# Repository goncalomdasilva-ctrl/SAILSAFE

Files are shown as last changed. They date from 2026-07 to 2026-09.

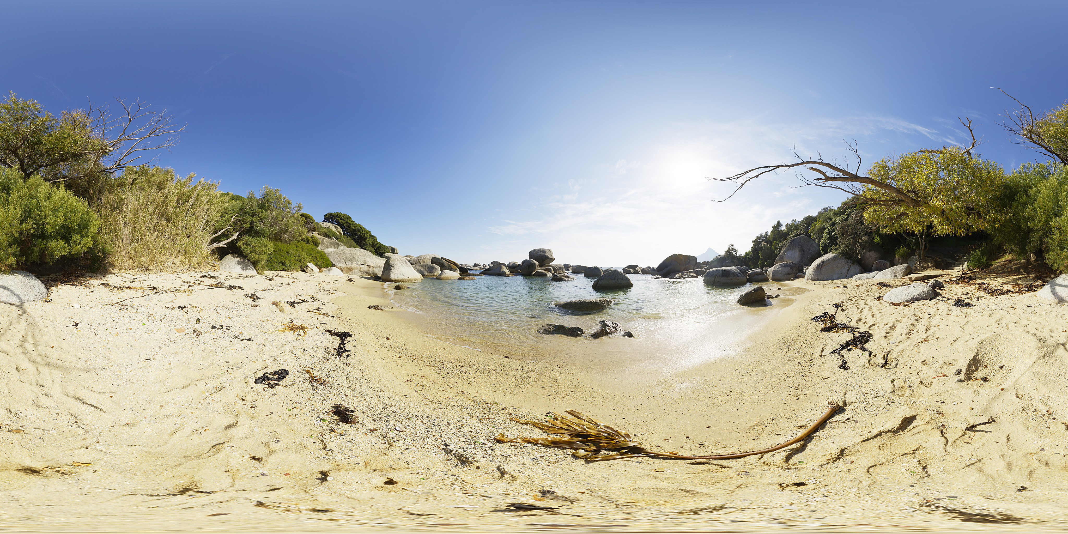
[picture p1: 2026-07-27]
website/assets/img/pano_mar.jpg

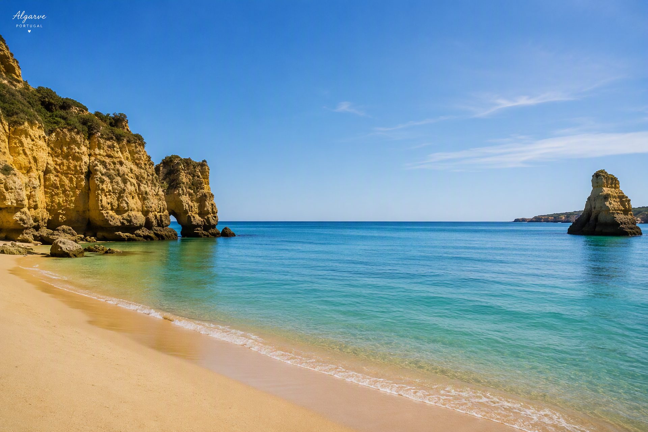
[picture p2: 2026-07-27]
website/assets/img/praia.jpg

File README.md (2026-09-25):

# SAILSAFE

Autonomous surface catamaran focused on control systems development.

## Overview
SAILSAFE is a personal engineering project focused on building an autonomous surface vehicle with differential propulsion, embedded control, and waypoint navigation. It is developed as a real-world platform for learning and applying control systems, embedded software and safety engineering.

> **Project history.** SAILSAFE has been in development since February 2026. The git
> history in this repository starts later than that — it was re-initialised during a
> restructure — so commit dates are not a record of the project's timeline. The actual
> development record, with dated entries from the start, is in
> [`Engineering_log.md`](Engineering_log.md).

> **On authorship.** The system design, the safety decisions, the hardware and the bench
> work are mine. The code is written with AI assistance and held to the same standard as
> everything else here: a regression suite that runs without hardware, and figures that
> come from measurements on the bench rather than from datasheets. The engineering log and
> the commit messages are also written with AI assistance, from my decisions and
> measurements. The log records those decisions and their reasoning — including the times
> a generated tool was wrong and the bench proved it.

## Current Phase
Phase 1 — software MVP validated in simulation, GPS integrated and validated on hardware. Propulsion on the bench next; mechanical build held until the structure is weighed (blueprint v6.1, CAD v6.4). **Where things stand and what comes next: see [Next steps](#next-steps) below and the latest entries of `Engineering_log.md`.**

## Current Status
- Raspberry Pi ↔ ESP32 command chain validated on the bench (USB serial, text protocol `L: x R: y`)
- State machine DISARMED ↔ ARMED / NAV with 5 Hz heartbeat; ESP32-side failsafe (~1 s timeout) confirmed with real hardware
- Heading hold (proportional controller) and waypoint navigation (haversine + bearing) validated in closed-loop simulation
- STOP retried until acknowledged by the ESP32; ARM/NAV refuse without proof the latch opened
- Control path independent of an interactive terminal (FIFO + `SIGUSR1`), so the process is
  commandable under systemd or `nohup`
- Per-session CSV logging with millisecond timestamps
- **GPS validated on hardware** (15 Sep): NEO-8M on the Pi's GPIO UART, 2 600 frames
  without a single bad checksum, fix with 8 satellites and HDOP 1.05. Short-term
  wander measured at ~30 cm over 10 s; slow drift over 10 min reached a 31 m × 4 m
  box at a window sill, with half the sky blocked — a pessimistic bound, to be
  re-measured on open water before the waypoint arrival radius is fixed
- **GPS integrated into the main process** (17 Sep, `--gps`): position read and
  logged in every state, not just NAV, so an ordinary bench session produces the
  dispersion data a separate script used to be needed for. Losing position in NAV
  leads to a safe state after a short tolerance; the return point is recorded at
  ARM. Rehearsed end to end against fake serial hardware (`tools/system_bench.py`),
  never yet against the real receiver
- **Heading blocked**: the BNO055 module is faulty (internal rail at 2.7 V with 4.7 V
  in, and ~0.4 mA of leakage on SDA, which poisoned the whole I2C bus). Replacement
  ordered; see `Engineering_log.md` for the diagnosis
- Power sense (ADS1015) written and covered by tests, and the chip answers reliably on
  the bus, but the dividers are not built yet — the PGA correction and the divider
  ratios stay theory until they are
- Mechanical architecture v6.1: batteries housed inside the hulls, IP66 electronics box at deck level
- Motors and ESCs in hand (each motor and waterjet is a single 107 g unit); loop key and fuse soldered. Bench test with the units **uncoupled** is next. Running them on water stays gated by the remote kill switch
- **Components weighed (25 Sep):** ~2.0 kg for everything except the structure, against 3.2 kg assumed by the CAD. The structure is still unweighed, so the total sits between 5.3 and 10.4 kg (waterline 33–65 mm). Battery bay floors raised from z=45 to **z=80**, which clears the whole range. Lighter propulsion may move the CG forward of the LCB and flip the trim to the bow, which would move the battery bays aft — to be decided after weighing the structure
- **30% throttle ceiling is per phase, not a constant:** bench 30%; tethered on water, higher; free running only with the remote kill switch. 30% throttle is roughly 30% of top speed (~0.5 m/s by a rough estimate), which a 1-knot current cancels
- GPS wiring closed (OPEN-005): NMEA on the Pi's GPIO UART, `/dev/serial0` at 9600
- Return point implemented (closes OPEN-006 on the point): the position is recorded
  once at ARM, averaged over validated fixes in a sliding window, and never rewritten.
  With `--gps`, ARM is refused without it. Straight-line return, which is only
  admissible on open water within sight of the operator. Recorded but not yet
  consumed — there is no return mode yet
- **Arrival radius is in debt to the GPS rate.** At 1 Hz, a position may legitimately
  be 2.5 s old; at the 3 m/s design speed that is 7.5 m of uncertainty, against a 4 m
  arrival radius. No staleness budget fixes this — raising the module to 5 Hz
  (`UBX-CFG-RATE`) is the condition for tightening the radius

## Next steps
*Updated 2026-09-25. The reasoning behind each item is in `Engineering_log.md`.*

1. **Bench test of ESCs and motors, uncoupled from the jets.** 30 A fuse, provided the
   holder's pigtail really is 14 AWG copper (not CCA); check polarity with a meter before
   the loop key goes in. 2–3 s pulses at 10–15%. Check rotation
   direction *before* coupling and mark the phase order. Measure the current. First run of
   the latch, failsafe, ceiling and confirmed STOP against real actuators.
2. **Thrust test in a tub**, jet submerged so the cooling loop primes, pulling on a spring
   scale. Replaces the speed estimate with a number.
3. **Weigh the structure** — a 3 mm okoumé offcut of known area, and the XPS. Then correct
   the mass table in `verify_concept.py` with measured values, recompute the CG, and
   decide the battery bay X position, confirm z=80, and the motor access hatch.
4. **Find the blueprint generator (OPEN-016)** and apply the changes to the drawing. Only
   then do the drawings go to the carpenter.

In parallel: run `main.py --gps --sim` on the Pi with the real receiver.
Blocked, nothing to do: replacement BNO055 board; remote kill switch (budget).

Open items: OPEN-014 (dead reckoning as observer, never actuator), OPEN-015 (bilge water
sensor per hull — the cooling loop puts pressurised water inside the hull), OPEN-016
(blueprint has no generator in the repo).

## Safety Design
- Boot always in a safe (DISARMED) state; STOP has absolute priority
- Two independent protection layers: Pi heartbeat + ESP32 failsafe-by-timeout
- Propulsion latch: the failsafe does not merely stop the motors, it locks propulsion.
  The lock only opens on an explicit `L: 0 R: 0`, so no path leads from "stopped by
  failure" back to "running" without passing through zero
- Confirmed STOP: the stop command is retried until the ESP32 acknowledges it, with the
  input buffer drained first so a stale ack cannot pass for a fresh confirmation. The
  whole budget (~0.24 s) sits well inside the 1 s failsafe timeout, so the two layers
  chain instead of competing. An unconfirmed STOP is loud and logged
- Arming requires proof: ARM and NAV only proceed if the ESP32 confirms the latch opened.
  No announcing ARMED without knowing propulsion is actually unlocked
- Control does not depend on a terminal: keyboard (when a tty exists), a control FIFO
  (`echo s > /tmp/sailsafe.ctl`) and `SIGUSR1` as STOP. The signal path is the only one
  that cannot be missing, which is why it carries the stop
- Firmware-enforced 30% power ceiling for bench testing
- Return trigger on the electronics battery: it drains on the clock rather than on
  thrust, and when it goes, radio, logging and control go together. The guard latches —
  a battery that recovers voltage once the load drops does not un-abort a mission — and
  refuses to decide at all on uncalibrated readings
- Losing position stops the boat, it does not send it home by dead reckoning. Retracing
  the outbound path blind was considered and declined: with no speed sensor and a
  magnetometer sitting next to the motors, the estimate would be steered by the least
  trustworthy sensor in the system with nothing left to check it against — and GPS error
  is bounded where dead-reckoning error is not. The decisive argument was that the
  condition making a blind return safe (a working radio link) is the same one that makes
  it unnecessary, since the operator can then simply drive the boat back. Dead reckoning
  is still worth running as an *observer*, so its error can be measured against GPS and
  reported; that is OPEN-014, and it never steers. Reasoning in `Engineering_log.md`
- Manual power cut (XT90 loop key) required before any ESC/motor energisation; remote kill switch (2.4 GHz RC / LoRa) planned before autonomous operation

## Main Components
- Raspberry Pi 4 (high-level control, navigation, logging — Python)
- ESP32 (real-time motor control and failsafe — C++/Arduino)
- 2 brushless motors with ESCs (waterjets)
- GPS NEO-8M, IMU BNO055, ADC ADS1015 — all three on the Pi (GPS on UART, the other two on I2C)

## Repository Structure
- `docs/` → architecture and project documentation
- `hardware/` → electrical and mechanical files (schematics, blueprints, CAD)
- `software/esp32/` → ESP32 firmware
- `software/raspberry_pi/` → onboard software (communication, control, sensors, safety, telemetry, tests)

## Raspberry Pi setup
Two firmware parameters are conditions for the system to work at all, not bench tweaks.
A reinstall without them gives a boat with no heading and no sense, and nothing reports
an error that points at the cause.

```
# /boot/firmware/config.txt
dtparam=i2c_arm=on              # without it /dev/i2c-1 does not exist
dtparam=i2c_arm_baudrate=10000  # the BNO055 clock-stretches and the Broadcom I2C
                                # controller mishandles it: corrupted reads, no error
enable_uart=1                   # without it /dev/serial0 does not exist
dtoverlay=disable-bt            # puts the PL011 on the GPIO; the mini-UART's baud rate
                                # follows the core clock and drifts with CPU load
```

Also, in `raspi-config` → Interface Options → Serial Port: login shell over serial **no**,
serial hardware **yes**. Verify what actually took effect, because a parameter that lands
inside a conditional section of `config.txt` is ignored in silence:

```bash
ls -l /dev/serial0     # must point at ttyAMA0, not ttyS0
i2cdetect -y 1         # 0x28 (BNO055) and 0x48 (ADS1015)
for f in /proc/device-tree/soc/i2c@*/clock-frequency; do
  echo -n "$f: "; od -An -tx1 "$f" | tr -d " \n"; echo
done                   # i2c@7e804000 must read 00002710 (10000)
```

Both I2C devices need their address pin tied by a wire — `ADD` to GND on the BNO055
(0x28), `ADDR` to GND on the ADS1015 (0x48). A floating address pin does not fail: it
gives an address that changes, and a device that appears and disappears.

Dependencies on the Pi:

```bash
pip install smbus2 pyserial adafruit-circuitpython-bno055 --break-system-packages
```

## Running the software (bench)
```bash
# unit tests (no hardware needed)
python3 software/raspberry_pi/tests/test_heading.py
python3 software/raspberry_pi/tests/test_mixer.py
python3 software/raspberry_pi/tests/test_navigation.py

python3 software/raspberry_pi/tests/test_real_heading.py
python3 software/raspberry_pi/tests/test_stop_confirmado.py
python3 software/raspberry_pi/tests/test_commands.py
python3 software/raspberry_pi/tests/test_sense.py
python3 software/raspberry_pi/tests/test_battery_guard.py
python3 software/raspberry_pi/tests/test_real_position.py
python3 software/raspberry_pi/tests/test_return_point.py

# ESP32 safety logic (runs on a PC, no board needed)
g++ -std=c++11 -Wall -o /tmp/tms software/esp32/tests/test_motor_safety.cpp && /tmp/tms

# firmware syntax check against stub Arduino headers (no board, no ESP32 toolchain).
# Catches typos and signature drift; NOT a substitute for a real build.
sh software/esp32/tools/syntax_check.sh
arduino-cli compile --fqbn esp32:esp32:esp32 software/esp32   # the real thing

# main process (ESP32 over USB optional)
python3 software/raspberry_pi/main.py               # DISARMED/ARMED only
python3 software/raspberry_pi/main.py --sim         # NAV in simulation, no propulsion sent
python3 software/raspberry_pi/main.py --sim-motores # NAV in simulation, motors DO run
```

186 Python tests and 182 C++ checks, none of which need hardware.

There is also an end-to-end rehearsal of the whole process against fake serial
hardware — two pseudo-terminals, one feeding NMEA as the NEO-8M, the other
answering STOP as the ESP32:

```bash
cd software/raspberry_pi
python3 -m tools.system_bench
```

It walks ARM-too-early → ARM → NAV → GPS going silent, and checks that each step
does the safe thing. Unit tests cover the pieces; this one covers the seams
between them, which is where the last three defects were.

### Bench tools
Each one exercises exactly one sensor and sends nothing to the ESP32.

```bash
cd software/raspberry_pi
python3 -m tools.heading_bench --fake     # BNO055: heading hold, turned by hand
python3 -m tools.sense_bench --fake       # ADS1015: channels, and one-point calibration
python3 -m tools.sense_bench --ganho-errado   # shows the saturation the wrong PGA causes
python3 -m tools.gps_bench --fake         # NEO-8M: fix quality, not just "has a position"
python3 -m tools.gps_bench --cru          # shows every frame, and whether it parsed
```

Drop `--fake` for the real sensor. `sense_bench --calibrar a2 12.60` stores the scale
factor for one channel against a multimeter reading; without that file the readings are
produced but marked uncalibrated, and the return trigger refuses to act on them.

```bash
# main process with the real GPS (position real, heading still synthetic)
python3 main.py --gps --sim
```

With `--gps` the position comes from the NEO-8M and is logged in every state. If the
port does not open the process **exits** rather than quietly falling back to the
synthetic boat — running a different system than the one that was asked for is the
failure nobody notices. Heading is still synthetic, so `nav_guard` keeps refusing
propulsion: `--gps --sim` is an observation mode, not a mission.

`gps_bench` reports four counters rather than one, because "this frame produced no
position" has causes with opposite remedies: **bad checksum** means corruption (baud,
wiring, ground); **no fix** means an intact frame that carries no position, which during a
cold start is every frame for minutes and is not a fault at all; **rejected** means a
position that failed the satellite, HDOP or null-island criteria; **accepted** means a
usable fix. Collapsing them into one number makes a normal cold start look like a wiring
failure.

### Commanding the process
`a`=ARM `n`=NAV `d`=DISARM `s`=STOP `q`=quit, over any of three paths:

```bash
# 1. keyboard, when a terminal is attached
# 2. control FIFO — works under systemd, nohup or a non-tty ssh
echo s > /tmp/sailsafe.ctl
# 3. signal — STOP only, and the one path that cannot be missing
kill -USR1 <pid>
```

Serial ports can be named explicitly: `--esp32-port /dev/serial/by-id/...` and
`--gps-port`. A stable `by-id` name is worth the typing — two USB devices swap
`/dev/ttyUSB*` numbers between boots, and nothing warns you.

The process prints its PID and the paths actually available at startup. Without a tty and
without a FIFO only STOP remains, so the boat cannot be armed — inert, which is the safe
direction to fail in.

`NAV` closes the control loop on a synthetic boat. Commanding real motors from it means
the physical boat follows a mission it has no knowledge of, so the mode refuses to start
unless the synthetic sources are declared on the command line. `--sim` computes and prints
the motor commands without sending them; `--sim-motores` actually drives the ESCs and is
only for a boat clamped to the bench, out of the water.

## Documentation
- System architecture: `docs/SAILSAFE_Architecture_v1_13.docx`
- Engineering log: `Engineering_log.md`
- Bench procedure (sensors): `docs/SAILSAFE_procedimento_sensores_v1.pdf`
- Mechanical blueprint: `hardware/mechanical/SAILSAFE_blueprint_madeira_v6_1.pdf`

## License
MIT — see `LICENSE`. Experimental project: build and operate at your own risk (see safety notice in the license file).

## Author
Gonçalo Martins da Silva

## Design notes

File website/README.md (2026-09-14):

# SAILSAFE — site do projeto

Site estático e bilingue (PT/EN) que apresenta o SAILSAFE, uma plataforma autónoma de superfície em catamarã, com um visualizador 3D interativo do modelo CAD.

Sem build, sem dependências de CDN, sem framework. Basta servir a pasta.

---

## Ver o site

### Sem instalar nada — `SAILSAFE.html`

Duplo clique em **`SAILSAFE.html`**. É um ficheiro único e autónomo, com o three.js,
o modelo 3D e todo o código embutidos. Funciona offline, sem servidor, sem CDN.

### Versão para publicar — `index.html`

Esta é a que vai para o GitHub Pages. Usa módulos ES e carrega o `.glb`
separadamente, por isso **tem de ser servida por HTTP** — o browser bloqueia
módulos em `file://`.

**Windows** — duplo clique em `serve.bat`. **macOS / Linux:**

```bash
python3 -m http.server 8000
```

Depois abre <http://localhost:8000>.

### Regenerar o ficheiro único

```bash
npm install esbuild
node build_standalone.mjs
```

---

## Publicar no GitHub Pages

1. Cria um repositório no GitHub e envia o conteúdo desta pasta para a raiz:

   ```bash
   git init
   git add .
   git commit -m "SAILSAFE project site"
   git branch -M main
   git remote add origin https://github.com/<utilizador>/<repositorio>.git
   git push -u origin main
   ```

2. No GitHub: **Settings → Pages → Build and deployment → Source: GitHub Actions**.

3. O workflow em `.github/workflows/deploy.yml` publica automaticamente a cada `push` para `main`.

O site fica em `https://<utilizador>.github.io/<repositorio>/`.

> O ficheiro `.nojekyll` está incluído para que o Jekyll não ignore pastas — não o apagues.

---

## Estrutura

```
.
├── SAILSAFE.html                 ficheiro único autónomo (duplo clique)
├── index.html                    versão modular, para GitHub Pages
├── build_standalone.mjs          gera o SAILSAFE.html
├── serve.bat                     servidor local para Windows
├── .nojekyll
├── .github/workflows/deploy.yml  publicação automática
└── assets/
    ├── sailsafe.glb              modelo 3D (41 peças · 6 960 triângulos · 408 kB)
    ├── css/style.css
    ├── js/
    │   ├── app.js                arranque, i18n, construção das secções
    │   ├── viewer.js             visualizador three.js
    │   ├── data.js               componentes, especificações, subsistemas
    │   └── i18n.js               textos PT / EN
    └── vendor/three/             three.js r169 (licença MIT incluída)
```

---

## O modelo 3D

`assets/sailsafe.glb` foi reconstruído a partir de `SAILSAFE_concept_v6_3.step` com as cotas exatas do ficheiro CAD. Face ao STEP original foram feitas cinco alterações, todas deliberadas:

1. **Cavidades reais abertas no casco** para os motores, veios, waterjets, ESCs e reforços de espelho de popa. No STEP estas peças estavam embebidas num bloco maciço sem booleana resolvida, o que impedia qualquer corte ou vista de secção.
2. **Arestas arredondadas com 4 mm** no casco e 1–3 mm nas restantes peças. Isto é mais fiel à construção real do que a aresta viva: as arestas e o fundo levam fita de fibra de vidro com epóxi, que não produz um canto vivo.
3. **Normais suavizadas por ângulo** (limite de 38°): as concordâncias ficam suaves e as arestas duras ficam nítidas. Sem isto o modelo lê-se como um bloco facetado.
4. **Coordenadas de textura** por projeção de caixa. O STEP não tinha nenhumas, e sem UVs não é possível aplicar materiais texturados.
5. **Materiais corrigidos.** O STEP declara todas as peças como aço a 7,85 g/cm³, o que é o valor por omissão do CAD e contradiz XPS, contraplacado e LiPo. Os materiais de render (gelcoat com clearcoat no casco, veio de madeira nas travessas, alumínio escovado nos motores, PCB nas placas) são gerados proceduralmente em `assets/js/materials.js`.

Nada mais foi alterado. Todas as posições, dimensões e relações entre peças são as do ficheiro original — verificadas peça a peça com tolerância de 0,05 mm.

Para regenerar o modelo a partir do STEP, ver `build_model.py` (requer `trimesh`, `manifold3d`, `scipy`, `numpy`).

---

## Funcionalidades do visualizador

- Órbita, zoom e enquadramento livre
- Ligar e desligar cada um dos cinco subsistemas
- Clicar em qualquer peça para ver descrição e especificações
- Cinco vistas predefinidas (isométrica, topo, lateral, proa, popa)
- Plano de água ao calado derivado para 6,2 kg
- Corte longitudinal pelo plano de simetria
- Vista explodida contínua
- Modo de cor por material ou por subsistema
- Iluminação de estúdio com envmap gerado em tempo de execução, sombras suaves e tone mapping ACES

---

## Nota sobre os dados

Cada valor apresentado no site está marcado com a sua origem:

| Marca | Significado |
|---|---|
| **Validado** | Medido ou confirmado em bancada |
| **Estimado** | Cálculo de arquitetura sobre datasheet, ainda sem medição |
| **Derivado** | Calculado a partir da geometria CAD |
| **Em aberto** | Decisão por tomar |

Os componentes de propulsão ainda não chegaram fisicamente ao projeto, pelo que nenhum número de desempenho é ainda uma medição em água. Esta separação é mantida deliberadamente.

---

## Créditos

Projeto pessoal de engenharia de **Gonçalo Martins da Silva**
Engenharia Eletrotécnica e de Computadores · Instituto Superior Técnico

Documentação de arquitetura v1.13 · modelo CAD v6.3

[three.js](https://threejs.org) r169 — licença MIT, incluída em `assets/vendor/three/LICENSE`.

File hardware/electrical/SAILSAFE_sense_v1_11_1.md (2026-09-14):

# Sense de tensão e corrente — especificação

Aplica-se ao circuito da caixa IP66 (U4 = ADS1015) do esquema elétrico v1.11.

## Revisões

| rev | data | alterações |
|---|---|---|
| 1 | 2026-07-25 | Versão inicial. Detetada a saturação do ADS1015 com o divisor 10k/2k2. |
| 2 | 2026-07-28 | Divisores passam a 5k/1k (resistores disponíveis). Canais reatribuídos: entra a tensão da bateria da eletrónica, sai a corrente do casco direito. Condensador de filtro passa a 2,2 µF. Bateria da eletrónica confirmada 3S 2200 mAh. |
| 3 | 2026-09-14 | Divisores passam a **10k/2k**, que é o par realmente em stock. **O rácio não muda:** 2/12 é o mesmo 1/6 que 1/(5+1), pelo que as tabelas de conversão, o fundo de escala, a resolução e o limite de saturação da revisão 2 continuam válidos sem uma única alteração. Mudam as duas grandezas que dependem dos valores absolutos e não do quociente: a impedância de fonte duplica (833 Ω → 1667 Ω), e com ela o condensador recomendado passa de 2,2 µF a 1 µF para o mesmo corte; a corrente permanente por divisor cai para metade. |

---

## 1. O problema original

Os divisores de sense estavam especificados a 10k/2k2, com rácio 0,180328. Uma LiPo 3S carregada
(12,6 V) dava **2,272 V** à entrada do ADS1015, acima do FSR por omissão de **±2,048 V**. O limite de
saturação referido à bateria era 11,36 V — ou seja, **toda a zona útil de descarga lia saturado** e a
bateria pareceria cheia até já ir a meio da descarga.

Não é uma avaria que se manifeste: o circuito está eletricamente são e a leitura é sempre plausível.
Só está errada.

## 2. Divisor adotado — 10k / 2k

Aproveitam-se resistores já disponíveis. Nenhuma compra necessária.

> **Porque é que a mudança de 5k/1k para 10k/2k não mexe em mais nada.** O que o circuito faz
> depende do rácio, e 2/(10+2) é exatamente o mesmo 1/6 que 1/(5+1). O fundo de escala continua
> em 24,6 V, a resolução em 12 mV e o limite de saturação em 12,29 V. Só duas grandezas mudam, e
> são as que dependem dos valores absolutos e não do quociente: a impedância de fonte duplica e a
> corrente permanente reduz-se a metade.

| | valor |
|---|---|
| Resistor superior (ao positivo) | 10 kΩ |
| Resistor inferior (à massa) | 2 kΩ |
| Rácio k | 0,16667 |
| PGA / FSR | **±4,096 V** (GAIN_ONE) — **não** o default de ±2,048 V |
| Fundo de escala referido à bateria | 24,6 V |
| Resolução | 12,00 mV (4,00 mV por célula numa 3S) |
| Impedância de fonte | 1667 Ω |
| Corrente permanente | 1,05 mA a 12,6 V |

Três divisores, portanto **3 × 10 kΩ e 3 × 2 kΩ**. Contar antes de começar a soldar: um divisor a
menos descobre-se com o ferro quente.

Tabela de conversão (3S):

| V bateria | V no ADC |
|---:|---:|
| 12,60 (cheia) | 2,100 |
| 11,10 (nominal) | 1,850 |
|  9,90 (vazia) | 1,650 |

### ⚠ A correção do PGA continua a ser obrigatória

Com 5k/1k o limite de saturação no FSR por omissão sobe para **12,29 V** — que ainda é **inferior a uma
3S carregada (12,6 V)**. Trocar o divisor não resolve o problema sozinho.

**O PGA tem de ser configurado para ±4,096 V (GAIN_ONE) no código.** Sem isso, o topo da carga continua
a ler saturado.

Margem para 4S: 16,8 V dá 2,800 V, dentro do FSR e bem abaixo do máximo absoluto de entrada
(VDD + 0,3 = 5,3 V). Uma futura passagem a 4S não obriga a mexer em hardware.

## 3. O erro dominante são os resistores, não o ADC

| Tolerância | Erro de rácio | Erro a 12,6 V |
|---|---|---|
| 1 % | 1,7 % | ±0,21 V |
| 5 % | 8,6 % | ±1,09 V |

A resolução do conversor (12 mV) é uma a duas ordens de grandeza melhor do que o erro dos resistores.
Gastar em resistores de precisão vale mais do que gastar em bits.

**Calibração de um ponto por canal é obrigatória**, seja qual for a tolerância: medir a tensão real com
multímetro, comparar com a leitura, guardar um fator de escala por canal em ficheiro de configuração.
Elimina praticamente todo o erro de ganho e permite usar resistores de 5 % com confiança.

## 4. Filtragem

Condensador em paralelo com o resistor inferior de cada divisor (SENSE→GND do respetivo circuito).
O canal A3 (corrente) não leva condensador: a saída do ACS758 é de baixa impedância e não há
resistor inferior com que formar o filtro. Filtrá-la exigiria um RC em série próprio, e isso fica
para quando o sensor existir.

Com a impedância de fonte de **1667 Ω** (era 833 Ω na revisão 2 e 1,80 kΩ na revisão 1):

| C | fc | τ |
|---|---|---|
| 0,47 µF | 203 Hz | 0,8 ms |
| **1,0 µF** | **96 Hz** ← recomendado | 1,7 ms |
| 2,2 µF | 43 Hz | 3,7 ms |
| 4,7 µF | 20 Hz | 7,8 ms |

**Qualquer valor entre 1 µF e 4,7 µF serve.** A tensão de bateria é um sinal lento e o tempo de
estabelecimento mais longo da tabela — 7,8 ms de constante de tempo, portanto menos de 70 ms para
estabelecer a 12 bit — é irrelevante para quem lê a bateria uma vez por segundo. O critério real é o
que houver na gaveta.

**Tipo de condensador.** Cerâmico X7R/X5R ou de filme, com tensão nominal de 16 V ou mais (aos
terminais do resistor inferior estão 2,1 V, mas um condensador barato a trabalhar perto do limite
perde capacidade). Um eletrolítico funciona, mas a sua corrente de fuga forma um caminho em paralelo
com o resistor inferior e desvia o rácio; se for o que houver, montá-lo **antes** de calibrar, para
a calibração o absorver.

**Sem condensador nenhum ainda dá para trabalhar.** O condensador existe para rejeitar o ruído de
comutação dos ESCs. Enquanto não houver ESCs a comutar — bancada com fonte de laboratório, ou com a
bateria mas sem propulsão — os divisores podem ser montados, lidos e calibrados sem ele. Passa a ser
obrigatório antes do primeiro ensaio com motores a girar, e a calibração deve ser refeita depois de
o pôr.

A tensão de bateria é um sinal lento; o corte a 87 Hz rejeita o ruído de comutação do ESC, que é a
fonte de ruído dominante a bordo.

## 5. Atribuição dos quatro canais

O ADS1015 tem quatro entradas. Um divisor custa cêntimos; um sensor de corrente custa euros. **O recurso
escasso é o canal, não o componente** — por isso gastam-se três canais em tensões e um em corrente.

| canal | sinal | sensor |
|---|---|---|
| A0 | Tensão do casco esquerdo | divisor 10k/2k |
| A1 | Tensão do casco direito | divisor 10k/2k |
| A2 | **Tensão da bateria da eletrónica (3S 2200)** | divisor 10k/2k |
| A3 | Corrente do casco esquerdo | ACS758-050U |

### Porque entra a bateria da eletrónica

As baterias esgotam-se em relógios diferentes: a da eletrónica consome-se com o **tempo decorrido**,
independentemente de o barco andar; as de propulsão só enquanto há impulso. Em qualquer utilização com
paragens, deriva ou navegação lenta, **a bateria da eletrónica esgota-se primeiro** (≈2,7 h a 7,2 W).

É também a falha mais grave: ao esgotar-se perdem-se rádio, registo e controlo em simultâneo, e o barco
fica à deriva sem posição conhecida. O esgotamento da propulsão deixa o barco parado mas localizável.

Este canal não é um mostrador — é o **gatilho de regresso**. Abaixo de um limiar, a missão é abortada.

### Porque sai a corrente do casco direito

Instrumentar um só casco introduz um erro aceitável no modelo de energia. Desequilíbrio entre cascos
medido em simulação:

| missão | desequilíbrio |
|---|---|
| linha reta | 0,0 % |
| ziguezague (viragens alternadas) | −1,6 % |
| missão de demonstração (1 viragem) | +8,9 % |
| quadrado (4 viragens do mesmo lado) | +13,6 % |

Medir um casco e duplicar dá um erro de cerca de **7 %** no total — abaixo da incerteza atual da
potência dos motores, que ainda não é conhecida.

**Limitação aceite:** um jato obstruído no casco não instrumentado não é detetado diretamente. Mitigação
parcial: a queda de tensão sob carga funciona como indicador indireto, calibrando no casco instrumentado
a relação entre queda e corrente e aplicando-a ao outro pela tensão.

### Sensor de corrente

ACS758-050U (Hall, isolado, unidirecional 0–50 A, 60 mV/A, offset 0,6 V).

| Corrente | Saída |
|---:|---:|
| 0 A | 0,600 V |
| 20 A | 1,800 V |
| 40 A | 3,000 V |

Cabe no mesmo FSR de ±4,096 V, com resolução de 33 mA por conta.

Ligação: o sensor fica no casco, em série com o positivo **a jusante da loop key e do relé** (mantém a
propriedade "0 V / 0 A = casco desarmado"). Atravessam a ponte apenas +5 V, GND_ELEC e a saída analógica
— sinais e alimentação de baixa corrente, pelo que a regra de nenhum cabo de potência atravessar a ponte
se mantém.

## 6. Limitações conhecidas

- **Não sobra canal para monitorizar o próprio rail de 5 V.** A saída do ACS758 é ratiométrica à sua
  alimentação enquanto o ADS1015 mede contra referência interna, portanto oscilações do 5 V desviam a
  leitura de corrente. Compensação exigiria um segundo ADS1015 (endereço alternativo pelo pino ADDR).
- **Casco direito sem medição de corrente** até haver segundo ADS1015 (OPEN-012).
- Se os servos dos bocais ficarem no rail de 5 V, os seus picos de corrente contaminam também a leitura.
- **O esquema elétrico v1.11 indica 2S 2200 mAh para a eletrónica; a bateria real é 3S 2200 mAh.**
  Correção pendente no KiCad.

## 7. Alterações a fazer no KiCad

1. Divisores a 10 kΩ / 2 kΩ, com **tolerância anotada** no campo do componente.
2. **Três** divisores: SENSE_E, SENSE_D e SENSE_ELEC (novo).
3. Condensadores de **1 µF** (ou o que houver entre 1 e 4,7 µF) em paralelo com o resistor inferior de cada divisor.
4. A3 do U4 ligado a ISENSE_E (ACS758). Casco direito sem corrente, documentado como reserva.
5. Corrigir o circuito da caixa IP66 para **LiPo 3S 2200 mAh**.
6. Nota junto de U4:
   `ADS1015 PGA = +-4.096 V (GAIN_ONE). Com o default de +-2.048 V a leitura satura acima de 12.3 V.`

## 8. Verificação quando houver hardware

- Varrer 9→13 V com fonte de bancada e confirmar que a leitura acompanha linearmente e **não satura**.
- Calibrar o fator de escala de cada um dos três canais de tensão contra multímetro.
- Medir o consumo real da eletrónica para fixar o limiar de regresso com margem de segurança.
- Só depois disto confiar em qualquer estimativa de estado de carga ou de autonomia.

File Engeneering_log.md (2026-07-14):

# Engineering Diary

A viabilidade do projeto SAILSAFE tem vindo a ser analisada desde fevereiro de 2026. Durante o período letivo, o foco esteve na exploração de opções de arquitetura, integração de subsistemas e definição dos principais requisitos técnicos.

Uma das tentativas iniciais incluiu o desenho de uma PCB para integração elétrica. Essa abordagem revelou-se inadequada para distribuição de potência, sobretudo pela ausência de planos de cobre e pela fase ainda inicial de experiência em desenho de PCBs. Ainda assim, essa tentativa foi útil para clarificar restrições do sistema e reforçar a decisão de adotar uma arquitetura elétrica mais conservadora e robusta.

Após várias iterações, foi definida uma arquitetura inicial suficientemente sólida para avançar para a fase de execução e validação experimental.

## 2026-07-05

### Trabalho realizado

* Preparação inicial do código do ESP32 antes da chegada dos ESCs e do Raspberry Pi.
* Criação do esquema elétrico v1.

### Problemas / limitações

* Curva de aprendizagem inicial do KiCad, com algum tempo necessário para compreender a ferramenta e estruturar corretamente o esquema.

### Resultado do dia

* Base inicial de firmware preparada.
* Primeira versão do esquema elétrico concluída.

### Próximo passo

* Refinar a arquitetura elétrica e continuar a consolidação da documentação principal.

## 2026-07-06

### Trabalho realizado

* Firmware inicial do ESP32 preparado.
* Esquema elétrico v1 fechado.
* Documentação principal do projeto atualizada.
* BOM consolidada.
* Estratégia de controlo inicial por Wi-Fi definida.
* Recebido o Raspberry Pi 4 para o projeto.
* Configurado cartão microSD de 32 GB com Raspberry Pi OS.
* Configurado acesso remoto por SSH.
* Atualizado o sistema operativo do Raspberry Pi.
* Ativadas as interfaces I2C e Serial.
* Instaladas ferramentas base de desenvolvimento: Python 3, pip, venv, git, i2c-tools, screen e minicom.
* Criada a estrutura inicial de pastas do projeto no Raspberry Pi.

### Decisões técnicas

* O kill-switch físico/remoto foi identificado como requisito futuro, mas adiado por motivos de orçamento.
* Foi decidido não ligar ainda ESCs, motores ou baterias de potência antes da validação da comunicação Raspberry Pi → ESP32.

### Problemas / limitações

* O KiCad não incluía vários módulos específicos necessários para o projeto, obrigando ao uso de conectores genéricos no esquema.
* O esquema elétrico ainda requer melhorias de representação, embora os pontos principais de arquitetura estejam definidos.
* A preparação inicial do Raspberry Pi exigiu adaptação de hardware disponível para configurar o microSD.

### Resultado do dia

* O projeto ficou num estado técnico muito mais sólido em termos de arquitetura, documentação e preparação para testes de bancada.
* O Raspberry Pi ficou operacional e preparado para integração futura com sensores e comunicação com o ESP32.
* O projeto encontra-se a aguardar a chegada dos componentes para iniciar testes físicos.

### Próximo passo

* Testar comunicação Raspberry Pi → ESP32 por USB.

## 2026-07-07

### Trabalho realizado

* Iniciada a criação do repositório GitHub do projeto SAILSAFE.
* Definida a estrutura inicial para documentação pública do projeto.
* Preparado o conteúdo inicial do README e da organização de ficheiros.
* Estruturados assistentes de IA para apoio à documentação, organização de tarefas e maior consistência na escrita técnica.

### Decisões técnicas

* Foi decidido começar com uma estrutura simples de repositório, suficientemente organizada para ser mantida sem fricção excessiva.
* A documentação pública será construída de forma incremental, em vez de tentar formalizar tudo de uma só vez.

### Problemas / limitações

* Curva de aprendizagem inicial do GitHub e da lógica de repositórios.
* Ainda sem integração total dos ficheiros técnicos no repositório.

### Resultado do dia

* O projeto passou a ter uma base inicial para documentação pública e portefólio técnico.
* Ficou definido um caminho mais claro para organizar arquitetura, software, hardware e registos de evolução.
* Os assistentes de IA passaram a integrar o processo como ferramenta de apoio à produtividade e revisão técnica, sem substituir validação própria.

### Próximo passo

* Fazer upload da documentação principal, esquema elétrico, ficheiro 3D e código do ESP32 para o repositório.

## 2026-07-08

### Trabalho realizado

* Validada comunicação Raspberry Pi 4 → ESP32 por USB (ligação detetada como /dev/ttyUSB0).
* Confirmada interface USB-série CH341 no sistema.
* Validada comunicação UART entre Raspberry Pi e ESP32.
* Confirmado formato de comando textual:
L:10 R:10
* Validada conversão interna no ESP32:
percentagem → PWM (ex.: 10% → 1100 µs).
* Confirmado funcionamento de failsafe por perda de input (timeout → motores parados).
* Criado script Python no Raspberry Pi para envio periódico de comandos (keep-alive).
* Reestruturado parser UART do ESP32 para abordagem não bloqueante baseada em buffer + newline.

### Problemas / limitações

* Cabo USB inicial não suportava dados (sem deteção do ESP32).
* Uso de screen causava envio inválido de comandos (carácter a carácter).
* Diferença entre documentação e implementação (PWM vs percentagem).
* Parser inicial (readStringUntil) introduzia risco de bloqueio.
* Conflito de acesso à porta série ao usar simultaneamente screen e Python.

### Decisões técnicas

* Manter arquitetura:

  * Raspberry Pi → controlo de alto nível
  * ESP32 → controlo em tempo real + failsafe
* Congelar protocolo atual:
comando textual em percentagem (L:x R:y + newline)
* Limitar output inicial a 0–30% para segurança em bancada.
* Usar keep-alive como mecanismo normal e failsafe como redundância.

### Resultado do dia

* Cadeia de controlo RPi → ESP32 validada em bancada.
* Protocolo básico de comando e segurança funcional.
* Base sólida estabelecida para integração futura com ESCs e motores.

### Próximo passo

* Validar repetibilidade do keep-alive e comando STOP.
* Evoluir comando para modelo throttle + steering.
* Só depois iniciar integração com ESCs, motores e testes de potência.

### 2026-07-10

#### Trabalho realizado

* Aquisição de material elétrico para preparação da montagem física do sistema.
* Compra de cabos elétricos com secções de 6 mm², 1,5 mm² e 0,75 mm².
* Compra de conectores Wago para ligações de baixa corrente e sinais.
* Compra do carregador para as baterias LiPo.
* Aquisição de consumíveis e acessórios necessários à futura montagem elétrica.

#### Decisões técnicas

* Reservar o cabo de 6 mm² para o circuito de potência: bateria de 5000 mAh, fusíveis, barramentos e alimentação dos ESCs.
* Reservar o cabo de 1,5 mm² para alimentação da eletrónica, entrada do conversor DC-DC e ligação de referência entre os negativos dos dois subsistemas.
* Reservar o cabo de 0,75 mm², ou os fios originais dos módulos, para sinais PWM, GND de sinal e sensores.
* Manter os Wagos limitados a ligações de baixa corrente e sinais, não os utilizando no caminho principal de corrente dos motores.

#### Resultado do dia

* Material elétrico principal obtido para iniciar a preparação e os testes de montagem.
* Cablagem disponível com secções diferenciadas para potência, eletrónica e sinais.

#### Próximo passo

* Definir a arquitetura mecânica dos cascos, a localização das caixas, dos ESCs e das passagens de cabos antes de cortar ou montar a estrutura definitiva.

### 2026-07-11

#### Trabalho realizado

* Revisão crítica da arquitetura mecânica e elétrica do primeiro protótipo.
* Definição preliminar de dois cascos em XPS de célula fechada, revestidos com fibra de vidro e resina epóxi.
* Definição de reforços locais em contraplacado nas popas, pontos de fixação das travessas, base da caixa central e ponto de recuperação por corda.
* Definição preliminar de dimensões: aproximadamente 800 mm de comprimento total, 350 mm de largura total, cascos com cerca de 100–110 mm de largura e 130–140 mm de altura.
* Definição de três travessas estruturais: frontal, central e traseira.
* Análise da passagem dos cabos por conduítes no interior das travessas e, depois, pela face superior/interior dos cascos, devidamente fixos e protegidos.
* Revisão da localização dos ESCs, passando a privilegiar a instalação de cada ESC próximo do respetivo waterjet para reduzir o comprimento dos três cabos de fase do motor.
* Consolidação da separação das duas baterias: LiPo 5000 mAh dedicada à propulsão e LiPo 2200 mAh dedicada à eletrónica através do conversor DC-DC.
* Clarificação da estratégia de GND comum entre potência e eletrónica.

#### Decisões técnicas

* Não ligar os positivos das duas baterias e não colocar as baterias em paralelo.
* Ligar o negativo da bateria de potência ao barramento negativo de potência e o negativo da bateria de eletrónica ao ponto de GND da eletrónica.
* Criar uma única ligação de referência, em estrela, entre o GND da eletrónica e o barramento negativo de potência.
* Manter os fios GND que acompanham os sinais PWM dos dois ESCs, sem depender exclusivamente destes fios finos para estabelecer o GND comum do sistema.
* Usar cabo de 6 mm² entre a distribuição de potência e cada ESC.
* Usar cabo de 1,5 mm² para a ligação única de referência entre o GND eletrónico e o barramento negativo de potência.
* Isolar os fios de 5 V/BEC dos ESCs, caso existam, enquanto a eletrónica for alimentada pelo conversor DC-DC dedicado.
* Não fixar os waterjets diretamente ao XPS; utilizar contraplacado reforçado na popa, laminado e selado, com parafusos, anilhas e vedação adequados.
* Manter os ESCs acessíveis, protegidos contra água e com possibilidade de dissipação térmica; não os encapsular permanentemente em foam ou epóxi.

#### Riscos e limitações identificados

* A estimativa inicial de massa de 1,8–2,2 kg pode ser otimista para o protótipo completo; a massa real deve ser medida durante a construção.
* O XPS sem laminação não possui resistência suficiente para impactos, parafusos ou cargas concentradas.
* Cabos exteriores mal fixos podem entrar na admissão dos waterjets, sofrer abrasão ou conduzir água para as caixas.
* A inexistência de kill-switch físico/remoto mantém a restrição de testes na água com corda de recuperação, potência limitada e supervisão direta.

#### Resultado do dia

* Conceito mecânico preliminar consolidado para uma construção híbrida: XPS + fibra de vidro + epóxi, com reforços estruturais em contraplacado.
* Percurso preliminar de cabos e localização dos ESCs definidos.
* Arquitetura de duas baterias e GND comum clarificada sem união dos positivos.
* Base técnica preparada para atualizar o documento de arquitetura para a versão v1.5.

#### Próximo passo

* Confirmar as dimensões físicas e a massa de todos os componentes.
* Fazer uma disposição à escala real em cartão antes de cortar XPS ou madeira.
* Confirmar o modelo exato, o procedimento de arming e a presença de BEC nos ESCs.
* Comprar os materiais mecânicos e de laminação após confirmar disponibilidade, compatibilidade e quantidades.

### 2026-07-12
 
#### Trabalho realizado
 
* Compra de contraplacado para os cascos e para a estrutura.
* Iteração de vários modelos CAD (.step); consolidada a versão v3 do modelo: caixas centrais ocas em contraplacado de 9 mm com tampas, placa base a distribuir a carga da pilha de caixas pelas travessas 1 e 2, componentes internos modelados (baterias, bus bars, fusível principal, Raspberry Pi 4, ESP32, DC-DC, BNO055, ADS1015, módulo GPS), antena GPS relocalizada para o topo da tampa e coberturas de proteção sobre os ESCs.
* Revisão do orçamento de massa com base nos volumes reais do modelo v3: ≈4,5–5,5 kg tal como modelado (madeira ≈2,6 kg, XPS ≈0,74 kg, fibra+epóxi ≈0,45 kg, restantes componentes ≈1,3 kg), invalidando a estimativa anterior de 1,8–2,2 kg.
* Análise de compatibilidade massa/potência: a 5,5 kg, ≈110 W/kg e impulso/peso estimado de 0,4–0,55 — adequado a navegação em deslocamento e ao OBJ-001; planeio excluído. Calado estimado ≈31 mm (≈6 mm/kg), favorável à submersão das admissões dos waterjets.
* Documento de arquitetura atualizado para v1.6: REQ-MEC-003, secções 5.3 e 17.2 e histórico de revisões.
* Conversor DC-DC colocado em funcionamento, com saída estimada em ≈5,1 V reais.
* Diagnóstico do multímetro: erro de escala consistente de ×1,86 confirmado com três referências independentes (LiPo a 11,8 V confirmados pelo carregador vs 22 lidos; pilha alcalina ~1,6 V vs 3,00 lidos; leitura do DC-DC coerente com o mesmo fator).
#### Decisões técnicas
 
* Alvo de saída do DC-DC fixado em 5,1 V (compensação da queda na cablagem até ao Raspberry Pi); ligação do Pi condicionada a verificação sob carga.
* Validação do DC-DC feita por medição comparativa contra referência conhecida, dado o erro de escala do multímetro; valores absolutos deste multímetro considerados não fiáveis até substituição.
* Meta de aligeiramento estrutural registada na v1.6: contraplacado de 5–6 mm nas caixas, travessas furadas ou em tubo de alumínio 20×20 e possível unificação das duas caixas (objetivo 3,5–4,0 kg).
#### Problemas / limitações
 
* Multímetro com leituras infladas por fator ≈1,86 (referência interna degradada); compartimento da pilha inacessível até agora, substituição pendente.
* As leituras erradas causaram falso alarme inicial (baterias aparentemente a 21–22 V e DC-DC aparentemente a 9,4–9,6 V), consumindo tempo de diagnóstico.
* A compra de contraplacado para os cascos pode implicar mudança da arquitetura de cascos (XPS + fibra → contraplacado), com impacto direto no orçamento de massa da v1.6; decisão ainda não formalizada.
#### Resultado do dia
 
* DC-DC operacional com saída estimada correta; baterias validadas como saudáveis (11,8 V confirmados pelo carregador).
* Modelo CAD v3 com componentes integrados e correções estruturais; documentação de arquitetura atualizada para v1.6 com orçamento de massa realista.
* Material estrutural (contraplacado) adquirido.
#### Próximo passo
 
* Adquirir multímetro fiável antes de qualquer teste com ESCs e motores.
* Verificar a saída do DC-DC sob carga e remedir a referência no fim da sessão.
* Decidir formalmente a arquitetura dos cascos (XPS + fibra vs contraplacado) e refazer o cálculo de massa antes de qualquer corte definitivo.
* Manter a disposição à escala real antes do corte, conforme definido a 2026-07-11.

### 2026-07-13
 
#### Trabalho realizado
 
* Consolidação física da cadeia de alimentação de 5 V: soldaduras reforçadas, fusível adicionado ao circuito e termorretráctil aplicado em todas as ligações.
* Validação da saída do conversor DC-DC: 5 V estáveis confirmados após a consolidação.
* Análise comparativa das duas vias de alimentação do Raspberry Pi 4: entrada USB-C (com cabo A-para-C descarnado) vs pinos GPIO (5 V nos pinos 2/4, GND nos pinos 6/14).
* Avaliação dos cabos disponíveis: cabo A-para-C descarnado considerado subdimensionado para a corrente do Pi 4 (condutores finos, retorno pela malha de blindagem); identificado cabo micro-B para a ligação Pi → ESP32.
* Definição do procedimento de identificação dos pinos GPIO com multímetro (continuidade pino 2 ↔ pino 4; continuidade pino 6 ↔ carcaça USB) e do procedimento de soldadura (solda no topo do pino, ≤3–4 s, termorretráctil, alívio de tensão com abraçadeira ao furo de montagem).
#### Decisões técnicas
 
* Alimentar o Raspberry Pi 4 pelos pinos GPIO (2/4 = +5 V; 6/14 = GND) com fio de 0,75 mm², usando os dois pares para dividir corrente e dar redundância mecânica; via USB-C mantida como alternativa.
* Alimentar o ESP32 exclusivamente pelo cabo USB a partir do Pi (dados + alimentação); não ligar VIN em simultâneo com USB.
* Instalar condensador eletrolítico (470–1000 µF, ≥10 V) junto ao ponto de entrega no Pi, como reservatório para picos de corrente; cerâmico de 100 nF a adicionar quando disponível.
* Riscos de soldadura identificados: ponte entre pino 2 (5 V) e pino 1 (3,3 V) é destrutiva; verificação final de continuidade 5 V↔GND e 5 V↔3,3 V obrigatória antes de dar corrente.
* Critério de aceitação da alimentação: vcgencmd get_throttled = 0x0 com o sistema em bateria.
#### Problemas / limitações
 
* Apenas disponível o condensador eletrolítico; o cerâmico de 100 nF fica pendente (impacto reduzido: filtra ruído de alta frequência, não afeta a estabilidade de tensão média).
* Multímetro de confiança ainda por adquirir; medições de corrente e verificações finais dependem dele.
#### Resultado do dia
 
* Cadeia de alimentação de 5 V consolidada e protegida (fusível + termorretráctil), com saída estável.
* Arquitetura de alimentação do par Pi/ESP32 decidida e documentada: DC-DC → GPIO do Pi; Pi → USB → ESP32.
* Procedimentos de identificação de pinos, soldadura e verificação definidos antes da execução.
#### Próximo passo
 
* Soldar os rabichos de 0,75 mm² aos pinos GPIO com o procedimento definido.
* Primeiro arranque do Pi em bateria; verificar get_throttled; só depois ligar o ESP32 e repetir.
* Testar o cabo micro-B (deteção de /dev/ttyUSB0) e correr keep-alive + failsafe integralmente em bateria.
* Comprar multímetro e condensador cerâmico de 100 nF.

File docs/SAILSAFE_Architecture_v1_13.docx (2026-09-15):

SAILSAFE: System Architecture

Gonçalo Martins da Silva

Instituto Superior Técnico (IST)

Engenharia Eletrotécnica e de Computadores

13 de setembro de 2026

Campo | Valor
Projeto | SAILSAFE — Barco Autónomo Catamarã
Tipo | Projeto pessoal de engenharia
Autor | Gonçalo Martins da Silva
Contexto académico | Estudante de Engenharia Eletrotécnica e de Computadores, Instituto Superior Técnico (IST)
Versão do documento | v1.13
Data | 2026-09-13

Estado

Sense do ADS1015 e leitor de GPS implementados e cobertos por testes, ainda sem hardware. Ligação do GPS fechada (OPEN-005): UART do GPIO em /dev/serial0 a 9600. Ponto de regresso definido (fecha OPEN-006 na parte do ponto; o trajeto é linha reta em plano de água aberto e à vista). Telemetria em tempo real continua futura e passa a estar explicitamente dependente da escolha do rádio (OPEN-011). Firmware gravado no ESP32 e ack da trava de propulsão confirmado por observação em bancada a 6 de agosto. Barramento I2C configurado e documentado (secção 22.7). Primeira ligação do BNO055 sem leitura válida: defeito fechado a 15 de setembro — o módulo está avariado e vai ser substituído (secções 22.8 e 22.9). GPS validado em hardware com dispersão medida (secção 22.10). Nova decisão em aberto: cerca virtual (OPEN-013).

Documento-mãe para organização técnica, validação de arquitetura, planeamento de testes e evolução do projeto.

# Histórico de Revisões

Versão | Data | Autor | Descrição
v1.0 | 2026-07-06 | Gonçalo Martins da Silva | Primeira versão profissional consolidada da arquitetura do sistema.
v1.3 | 2026-07-06 | Gonçalo Martins da Silva | Correções de consistência: versão do documento, ADS1015, GPS NEO-8M, arquitetura inicial das baterias e restrição de testes sem kill-switch.
v1.3.1 | 2026-07-06 | Gonçalo Martins da Silva | Secção 7.2 adicionada: controlo inicial por Wi‑Fi, interface web e evolução para antena externa/telemetria.
v1.3.2 | 2026-07-06 | Gonçalo Martins da Silva | Configuração inicial do Raspberry Pi: microSD, Raspberry Pi OS, SSH, atualização do sistema, ativação I2C/Serial, ferramentas base e estrutura inicial de pastas do projeto.
v1.4 | 2026-07-09 | Gonçalo Martins da Silva | Validação inicial bancada Raspberry Pi 4 ↔ ESP32 por USB concluída: deteção CH341 em /dev/ttyUSB0, parser UART não bloqueante revisto, comando atualizado para percentagem (formato L:10 R:10), script Python de keep-alive a 5 Hz no Raspberry Pi e confirmação do failsafe por timeout.
v1.5 | 2026-07-11 | Gonçalo Martins da Silva | Consolidação preliminar da arquitetura mecânica em XPS + fibra + epóxi, reforços locais em contraplacado, ESCs próximos dos waterjets, encaminhamento de cabos e estratégia de duas baterias com GND comum em estrela e positivos separados.
v1.6 | 2026-07-12 | Gonçalo Martins da Silva | Revisão do orçamento de massa com base no modelo 3D v3 (4,5–5,5 kg tal como modelado; meta 3,5–4,0 kg), análise de compatibilidade massa/potência dos motores 2440 KV4500 e atualização de REQ-MEC-003, secções 5.3 e 17.2.
v1.7 | 2026-07-14 | Gonçalo Martins da Silva | Construção de casco revista: pele de contraplacado 3 mm colada sobre XPS com fita de fibra nas arestas/fundo e selagem epóxi, em substituição da laminação integral; caixa de eletrónica passa a IP66 comercial 204×155×100 com bucins; longarinas de convés 20×10; cablagem caixa→ESC em conduíte corrugado; orçamento de massa v1.7 (modelo v4) e secção 18.
v1.8 | 2026-07-14 | Gonçalo Martins da Silva | Pele de casco revista para híbrida após medição do modelo (proa em cunha 3D: contraplacado 3 mm só nas zonas planas, proa laminada em fibra); caixa de baterias em contraplacado de 3 mm com ripas e cotas corrigidas (extremo = 180 − 2×espessura); nova subsecção 18.4 com regras de segurança LiPo; orçamento de massa v1.8 (≈6,2 kg).
v1.9 | 2026-07-15 | Gonçalo Martins da Silva | Integração da alimentação do Raspberry Pi 4: condensador eletrolítico e cabos soldados aos pinos GPIO; procedimento de validação USB-C para bateria/DC-DC; registo da corrupção lógica do microSD após corte de alimentação e recuperação por regravação do Raspberry Pi OS. Correção da referência residual da caixa de baterias de 9 mm para 3 mm reforçado.
v1.10 | 2026-07-17 | Gonçalo Martins da Silva | Integração da arquitetura de segurança temporária da Fase 1 com loop key XT90, atualização de segurança, plano de testes, riscos, dimensionamento do fusível principal e estado do kill-switch remoto.
v1.11 | 2026-07-23 | Gonçalo Martins da Silva | Consolidação v6/v6.1: baterias de propulsão alojadas nos cascos (z_G de ≈142 para ≈107 mm), segunda LiPo 5000, loop keys por ramo, blueprint madeira v6.1 (correção do túnel/caixa IP66, escotilhas com insertos M4 e junta de neopreno, sequências de serviço); estado do software: máquina de estados DISARMED/ARMED/NAV, heading hold, navegação por waypoints e logging CSV, validados em simulação com comunicação real ao ESP32; kill-switch remoto definido como RC 2,4 GHz ou LoRa com heartbeat; estratégia de dados: buffer circular + ficheiro sequencial a bordo, SQLite em terra.

v1.12

2026-07-28

Gonçalo Martins da Silva

Arquitetura do kill-switch remoto fechada (OPEN-008): corte por relé na linha positiva de cada casco, a jusante do fusível e da loop key, comandado por canal PWM de rádio que não atravessa o Pi nem o ESP32. Bateria da eletrónica confirmada como LiPo 3S 2200 mAh (o esquema elétrico v1.11 indica 2S — erro a corrigir) e identificada como o recurso crítico: esgota-se ao relógio e não ao andar, pelo que passa a ser monitorizada e a servir de gatilho de regresso. Sense do ADS1015 reatribuído a três tensões e uma corrente, com divisores 10k/2k. Modo NAV passa a seguir o bearing do WaypointNav; 18 testes automáticos.

v1.13

2026-09-14

Gonçalo Martins da Silva

Sense do ADS1015 implementado em software (PGA reafirmado a cada conversão, saturação tratada como ausência de medição, canal não instalado a devolver ausência e não zero) e gatilho de regresso implementado como guarda latching que recusa decidir sem calibração. Leitor de GPS NMEA com rejeição por checksum, satélites, HDOP, posição nula e idade do fix. OPEN-005 fechada: GPS na UART do GPIO. OPEN-006 fechada na parte do ponto de regresso, que passa a ser a posição registada no ARM a partir de fixes validados; trajeto em linha reta assumido como limitação desta fase. OPEN-007 mantida em aberto e ligada a OPEN-011. 149 testes em Python e 182 verificações em C++. Divisores de sense a 10k/2k em vez de 5k/1k, com o mesmo rácio de 1/6 e, portanto, sem qualquer alteração às tabelas de conversão; condensador de filtro recomendado passa a 1 µF. Acrescenta a configuração do barramento I2C no Raspberry Pi (dtparam de ativação e de baudrate, com a razão do clock stretching do BNO055) e o registo do defeito em aberto na primeira ligação dos sensores. Fecha o defeito da primeira ligação do BNO055 (módulo avariado) e acrescenta a nota de aquisição e integração do sensor de substituição, incluindo o link de I2C a fechar na placa da Devantech. Acrescenta a primeira medição de dispersão do GPS, marcada como limite superior provisório, e abre OPEN-013 (cerca virtual).

# Resumo Executivo

O SAILSAFE é uma plataforma autónoma de superfície em formato catamarã, concebida como projeto pessoal de engenharia para integrar eletrónica de potência, sistemas embebidos, navegação por GPS, sensores inerciais, controlo diferencial e documentação técnica estruturada. A embarcação terá aproximadamente 80 cm de comprimento, 35 cm de largura e massa estimada, após revisão do orçamento de massa (v1.8), entre 6,0 kg e 6,5 kg tal como configurado (cascos XPS com pele híbrida — contraplacado 3 mm nas zonas planas e proa laminada em fibra —, caixa de baterias em contraplacado de 3 mm com ripas e caixa de eletrónica IP66), com meta otimizada de ≈5,0 kg após aligeiramento das travessas.

A arquitetura proposta separa claramente a lógica de alto nível, executada num Raspberry Pi 4, do controlo de baixa latência e segurança dos motores, executado num ESP32. A propulsão é baseada em dois waterjets independentes, cada um controlado por um ESC brushless. Esta configuração permite viragem por controlo diferencial, aumentando ou reduzindo a potência relativa entre o lado esquerdo e o lado direito.

Este documento consolida a arquitetura do sistema, os requisitos iniciais, a distribuição elétrica, a organização de software, a estratégia de testes, os riscos técnicos e a estrutura documental recomendada. O objetivo é transformar o projeto numa referência técnica sólida, adequada para portfólio, acompanhamento académico, futura tese ou demonstração a professores e recrutadores.

# 1. Âmbito do Documento

Este documento é o documento-mãe do projeto SAILSAFE. A versão atual pretende concentrar, numa única peça técnica, a visão global do sistema. À medida que o projeto evoluir, este documento deverá ser separado em documentos especializados: arquitetura elétrica, arquitetura de software, arquitetura mecânica, plano de testes, registo de riscos e diário de engenharia.

- Definir a visão técnica e funcional do barco autónomo.
- Documentar a arquitetura de alto nível e os principais subsistemas.
- Registar requisitos, interfaces, componentes e decisões técnicas.
- Criar uma base profissional de documentação para evolução futura.
- Evitar decisões implícitas e tornar as ligações entre blocos verificáveis.

# 2. Objetivos do Projeto

O projeto tem objetivos técnicos, académicos e de desenvolvimento pessoal.

ID | Objetivo | Descrição
OBJ-001 | Navegação autónoma por waypoints | Desenvolver uma embarcação capaz de seguir pontos GPS de forma autónoma numa fase posterior.
OBJ-002 | Controlo diferencial | Controlar dois waterjets independentes para permitir manobra por diferença de potência.
OBJ-003 | Arquitetura modular | Separar navegação, controlo de motores, sensores, alimentação e segurança em blocos independentes.
OBJ-004 | Segurança operacional | Implementar failsafe para paragem dos motores em caso de perda de comunicação ou comandos inválidos.
OBJ-005 | Aprendizagem multidisciplinar | Desenvolver competências em eletrónica, programação, controlo, sistemas embebidos, integração e documentação.
OBJ-006 | Base para evolução futura | Permitir integração futura de telemetria, visão computacional, rádio/4G/5G e algoritmos avançados.

## 2.1 Fora de Âmbito (Fase 1)

As capacidades seguintes foram consideradas e adiadas de forma consciente, para manter o foco da Fase 1 na entrega de um veículo funcional e testado. Ficam registadas aqui para que a omissão não seja lida como uma lacuna não identificada.

- Deteção de obstáculos/pessoas (ultrassons, câmara, LIDAR) — o barco opera sempre em contexto supervisionado e a curta distância nesta fase.
- Redundância de hardware (computador, bateria, comunicação) — a decidir com base em dados reais de falha recolhidos nas Fases 1/2, não antecipadamente.
- Kill‑switch físico/remoto independente — arquitetura fechada na v1.12 (OPEN-008) mas ainda por montar, por decisão de sequência: primeiro pôr o sistema a funcionar com o barco preso e ao alcance da mão, onde a loop key basta como corte manual. Continua obrigatório antes de qualquer ensaio sem corda, autonomia livre ou operação afastada da margem.
- Telemetria remota (4G/LTE) e algoritmos de IA — fora de âmbito da Fase 1; o objetivo imediato é validar a arquitetura base, não adicionar complexidade que atrasaria o veículo funcional.

Nesta fase, a recuperação em caso de falha do barco é feita manualmente pelo operador (o barco opera perto o suficiente para ser recuperado a nadar), o que substitui, para já, a necessidade de redundância ou de deteção autónoma de falhas.

# 3. Requisitos do Sistema

Os requisitos seguintes representam a versão inicial do sistema. Alguns valores deverão ser refinados após medições reais, testes de bancada e testes em água.

ID | Categoria | Requisito | Valor / Critério
REQ-GEN-001 | Geral | Nome do projeto | SAILSAFE
REQ-GEN-002 | Geral | Tipo de embarcação | Catamarã autónomo elétrico
REQ-MEC-001 | Mecânico | Comprimento previsto | 80 cm
REQ-MEC-002 | Mecânico | Largura prevista | 35 cm
REQ-MEC-003 | Mecânico | Massa estimada | 6,0–6,5 kg (orçamento de massa v1.8: pele híbrida 3 mm/fibra, caixa de baterias 3 mm com ripas, caixa IP66); meta otimizada ≈5,0 kg. Compatível com os motores 2440 KV4500 em regime de deslocamento (ver 5.3); estimativas anteriores de 1,8–2,2 kg e 4,5–5,5 kg substituídas.
REQ-PROP-001 | Propulsão | Número de waterjets | 2
REQ-PROP-002 | Propulsão | Tipo de controlo | Controlo diferencial através de ESCs brushless
REQ-ELE-001 | Energia | Baterias previstas | LiPo 3S 11,1 V 5000 mAh e LiPo 3S 11,1 V 2200 mAh
REQ-ELE-002 | Energia | Separação potência/eletrónica | Obrigatória
REQ-ELE-003 | Energia | GND comum | Obrigatório entre potência, eletrónica e sinais dos ESCs
REQ-SENS-001 | Sensores | GPS | Módulo GPS NEO-8M completo com antena ativa
REQ-SENS-002 | Sensores | IMU | BNO055
REQ-SENS-003 | Sensores | ADC | ADS1015 (ADC 12-bit I2C)
REQ-SW-001 | Software | Failsafe de comunicação | Heartbeat / keep-alive periódico enviado pelo Raspberry Pi ao ESP32. Implementação bancada validada a 5 Hz (200 ms). Failsafe de firmware atualmente configurado para 1 s sem comando válido; valor final a congelar após testes com ESCs.
REQ-SW-002 | Software | Validação de comandos | Comandos fora do formato ou fora do limite seguro devem ser rejeitados e provocar estado seguro. Implementação atual: comando textual em percentagem.
REQ-TEST-001 | Testes | Sequência de validação | ESP32 isolado → 1 ESC → 2 ESCs → waterjets → barco preso em água → autonomia.

# 4. Visão Geral do Sistema

A arquitetura do SAILSAFE é distribuída: o Raspberry Pi 4 atua como computador de bordo e o ESP32 atua como controlador de tempo real dos motores. Esta separação reduz o risco de atrasos do sistema operativo do Raspberry Pi afetarem diretamente o controlo dos ESCs.

PC / Portátil

│

│ Wi‑Fi / SSH / Telemetria futura

▼

Raspberry Pi 4

┌────────────┼────────────┐

│ │ │

GPS BNO055 ADS1015

│ │ │

└─────── Sensores ───────┘

│

│ USB Serial ou UART

▼

ESP32

┌───────┴───────┐

│ │

PWM_LEFT PWM_RIGHT

│ │

▼ ▼

ESC Esquerdo ESC Direito

│ │

Waterjet Esq. Waterjet Dir.

## 4.1 Função de cada controlador

Controlador | Responsabilidades principais
Raspberry Pi 4 | Navegação de alto nível, leitura de GPS, leitura de IMU, leitura de ADC, cálculo de rumo, gestão de waypoints, logging, telemetria e interface futura.
ESP32 | Receção de comandos do Raspberry Pi, validação de comandos, geração PWM para ESCs, failsafe, watchdog e paragem segura dos motores.

# 5. Arquitetura Elétrica

O sistema elétrico deve manter uma separação clara entre potência e eletrónica. Os waterjets e ESCs devem trabalhar através de cabos adequados, fusíveis e bus bars. Os Wagos ou bornes devem ser usados apenas em sinais e baixa corrente, nunca como caminho principal da corrente dos motores.

Bateria de potência (+)

│
Loop Key (manual kill)
│

│

Fusível principal 100 A

│

Bus bar positivo

│

├── Fusível ESC esquerdo ── ESC esquerdo ── Waterjet esquerdo

│

├── Fusível ESC direito ── ESC direito ── Waterjet direito

│

└── Fusível eletrónica ── DC‑DC 5 V ── Raspberry Pi / ESP32 / Sensores

Bateria de potência (−)

│

Bus bar negativo

│

├── ESC esquerdo BAT−

├── ESC direito BAT−

└── GND comum da eletrónica

Rede / Sinal | Descrição | Observações
VBAT / BAT+ | Positivo da bateria de potência | Distribuído através do bus bar positivo e protegido por fusíveis.
BAT− / GND potência | Negativo da bateria de potência | Retorno de corrente dos ESCs e referência comum do sistema.
5V | Saída do conversor DC‑DC | Alimenta Raspberry Pi, ESP32 e módulos compatíveis.
3V3 | Alimentação lógica de sensores | Pode vir do Raspberry Pi ou de regulador adequado.
GND_E | GND da eletrónica | Deve ligar ao bus bar negativo para referência comum.
PWM_ESQ | Sinal PWM para ESC esquerdo | Gerado pelo ESP32.
PWM_DIR | Sinal PWM para ESC direito | Gerado pelo ESP32.
SDA / SCL | Barramento I2C | Partilhado por BNO055 e ADS1015.
UART_TX / UART_RX | Comunicação série | Dedicada exclusivamente ao GPS — a comunicação Raspberry Pi ↔ ESP32 passou a ser feita por USB‑C.

## 5.1 ESCs e Waterjets Brushless

Cada ESC brushless deve ser representado no esquema como um bloco com entradas de potência, entrada de sinal e três saídas de fase para o motor. O motor brushless não tem GND próprio; tem três fases U, V e W.

Pino do ESC | Ligação | Função
BAT+ | Bus bar positivo através de fusível | Alimentação positiva do ESC.
BAT− | Bus bar negativo | Retorno de potência do ESC.
PWM | GPIO do ESP32 | Comando de velocidade/posição para o ESC.
GND_SIG | GND do ESP32 / GND comum | Referência elétrica do sinal PWM.
U | Motor brushless | Fase U do motor.
V | Motor brushless | Fase V do motor.
W | Motor brushless | Fase W do motor.

## 5.2 Gestão de Energia e Baterias

As baterias previstas são LiPo 3S de 11,1 V, com capacidades de 5000 mAh e 2200 mAh. A arquitetura inicial define a bateria de 5000 mAh como bateria de potência para os ESCs/waterjets, e a bateria de 2200 mAh como bateria da eletrónica através do conversor DC‑DC de 5 V. Esta decisão mantém-se sujeita a validação por medições reais de corrente, autonomia e queda de tensão durante os testes.

Item | Valor atual | Estado
Bateria 1 | LiPo 3S 11,1 V 5000 mAh | A confirmar em montagem final
Bateria 2 | LiPo 3S 11,1 V 2200 mAh | A confirmar em montagem final
Conversor DC‑DC | 5 V para eletrónica | Selecionado/esquematizado
Fusível principal | 100 A | Estimativa baseada em dimensionamento teórico (2× ESC 40A); valor a validar após medições reais de corrente (TEST-XXX)
Fusíveis ESCs | 35–40 A por ramo (validado com motor 2440 KV4500, ESC 40 A) | Confirmado com especificação do motor/ESC
Fusível eletrónica | 10 A | Valor inicial conservador

## 5.3 Motores e Capacidade de Peso

Os motores brushless adotados são do tipo 2440 KV4500 (diâmetro 24 mm, comprimento 40 mm), com potência nominal de 300 W cada, tensão de trabalho de 7,4–11,1 V (2S–3S) e corrente recomendada compatível com ESCs de 40 A. Este motor é habitualmente usado em kits de waterjet para embarcações de 40 a 110 cm, o que coloca o casco do SAILSAFE (80 cm) dentro da gama recomendada, mas na zona mais leve dessa gama.

O orçamento de massa foi revisto (v1.7) com base nos volumes reais do modelo 3D v4 e na configuração atual: estrutura em madeira ≈1,9 kg (travessas maciças 0,95 kg; caixa de baterias em 3 mm com ripas ≈0,30 kg; placa base 0,27 kg; inserts, coberturas e longarinas 0,35 kg), pele dos cascos em contraplacado de 3 mm nas zonas planas ≈0,95 kg, laminação da proa + fita de fibra nas arestas/fundo + selagem epóxi ≈0,40 kg, cascos XPS ≈0,74 kg, caixa de eletrónica IP66 (204×155×100) ≈0,40 kg, baterias ≈0,57 kg, propulsão (motores, waterjets, ESCs) ≈0,47 kg, eletrónica ≈0,14 kg, cablagem/conduíte/bucins/fusíveis/busbars ≈0,45 kg e fixações/vedantes ≈0,20 kg — total ≈6,2 kg tal como configurado (intervalo 6,0–6,5 kg), com meta de ≈5,0 kg aligeirando as travessas (tubo de alumínio 20×20 ou furos) e otimizando a pele (aberturas no convés sob as caixas). Com os 2 motores combinados (600 W), o rácio potência/peso é ≈97 W/kg a 6,2 kg e ≈110–120 W/kg na meta otimizada. Conclusão de compatibilidade: a 6,2 kg o sistema mantém navegação em regime de deslocamento com autoridade de controlo diferencial adequada (impulso estático estimado de 2–3 kgf combinados, rácio impulso/peso ≈0,30–0,45), suficiente para o OBJ-001; navegação em planeio fica excluída, tanto pela massa como pela forma dos cascos. A velocidade de casco para 0,8 m de linha de água é ≈1,1 m/s, superável pelos cascos esbeltos do catamarã até ≈2 m/s estimados. O calado a 6,2 kg é ≈35 mm (área de flutuação 0,176 m²; ≈6 mm por kg), o que favorece a submersão das admissões dos waterjets e mantém ≈111 mm de bordo livre (altura de casco com pele: 146 mm). A corrente máxima combinada é ≈54 A (fusíveis de ramo de 35–40 A adequados; autonomia a plena potência ≈5–6 min com 5000 mAh, irrelevante operacionalmente); em cruzeiro limitado a 30 % estima-se 30–60 min por carga, a validar por medição. Este valor é uma estimativa de arquitetura baseada em datasheet, não em medição. Os componentes (motores, ESCs, baterias) ainda não chegaram fisicamente ao projeto; assim que a montagem inicial estiver disponível, os valores de empuxo, corrente e autonomia desta secção devem ser substituídos por medições reais (ver TEST-001 a TEST-005).

# 6. Sensores e Perceção

Sensor/Módulo | Interface | Ligação principal | Função
GPS NEO-8M | UART | UART do GPIO (/dev/serial0), TX/RX cruzados + 3V3 + GND | Posição para navegação por waypoints e para o ponto de regresso. 9600 8N1, NMEA. Fecha OPEN-005.
BNO055 | I2C | SDA/SCL + 3V3 + GND | Orientação, heading, inclinação e dados inerciais.
ADS1015 | I2C | SDA/SCL + VDD + GND | Tensão dos dois cascos e da bateria da eletrónica (divisores 10k/2k) e corrente do casco esquerdo (ACS758-050U, por instalar). PGA obrigatoriamente a ±4,096 V.

## 6.1 Barramento I2C

O BNO055 e o ADS1015 partilham os mesmos fios SDA e SCL do Raspberry Pi. O Raspberry Pi distingue os dispositivos através dos endereços I2C.

Raspberry Pi GPIO2 / SDA1 ─────┬──── BNO055 SDA

└──── ADS1015 SDA

Raspberry Pi GPIO3 / SCL1 ─────┬──── BNO055 SCL

└──── ADS1015 SCL

Raspberry Pi 3V3 ──────────────┬──── BNO055 VCC

└──── ADS1015 VDD

Raspberry Pi GND ──────────────┬──── BNO055 GND

└──── ADS1015 GND

# 7. Arquitetura de Software

O software deve ser organizado por responsabilidades. O Raspberry Pi deve tratar de navegação, sensores, logging e decisões de alto nível. O ESP32 deve tratar de controlo direto dos motores, validação e segurança.

Subsistema | Responsabilidade | Estado inicial
Raspberry Pi / Navigation | Cálculo de waypoint, rumo desejado, distância e decisão de velocidade. | A implementar quando o Raspberry Pi estiver operacional.
Raspberry Pi / GPS | Leitura e validação de dados GPS. | A implementar com módulo NEO-8M.
Raspberry Pi / IMU | Leitura do BNO055 por I2C. | A implementar.
Raspberry Pi / Logging | Registo em CSV de dados de navegação e comandos. | Planeado.
ESP32 / Motor Control | Geração PWM para ESC esquerdo e direito. | Base já testada em ambiente inicial.
ESP32 / Safety | Failsafe por perda de comunicação e rejeição de comandos inválidos. | Lógica inicial já definida/testada.
Comunicação Pi–ESP32 | Envio de comandos L/R por USB‑C (Serial sobre USB), com porta fixada por regra udev. | Formato inicial definido; ligação USB‑C confirmada.

## 7.1 Formato de Comando Inicial

O formato atual de comando para o ESP32 foi simplificado para percentagem, mantendo tradução interna para microsegundos de PWM no firmware.

Formato atual validado em bancada: L:10 R:10

Exemplos:

L:0 R:0 → stop / neutro

L:10 R:10 → ambos os lados a 10 %

L:12 R:8 → correção diferencial simples

### 7.2 Comunicação Inicial por Wi‑Fi e Interface de Controlo

Na fase inicial, o SAILSAFE poderá ser pilotado localmente por Wi‑Fi, usando o Raspberry Pi 4 como ponto de acesso ou como cliente numa rede próxima. O operador liga um portátil ou telemóvel à rede do Raspberry Pi e acede a uma interface web simples para enviar comandos manuais de teste.

Esta solução permite reduzir custos na Fase 1, evitando a compra imediata de um sistema RC completo, mantendo ainda assim uma forma prática de comando local durante testes supervisionados.

Arquitetura funcional inicial:

Portátil / Telemóvel
│
│ Wi‑Fi
▼
Raspberry Pi 4
│
│ USB Serial / USB‑C
▼
ESP32
│
├── PWM_ESC_ESQ → ESC esquerdo → Waterjet esquerdo
└── PWM_ESC_DIR → ESC direito → Waterjet direito

A interface web deverá incluir, no mínimo, comandos de frente, esquerda, direita, stop, seleção de potência limitada e indicação do estado de comunicação. O botão STOP deve estar sempre visível e acessível.

O Raspberry Pi recebe os comandos da interface e converte-os para o formato série já definido para o ESP32, por exemplo L:<valor> R:<valor>. O ESP32 continua responsável pela validação dos comandos, geração de PWM, watchdog e paragem segura dos motores.

Limitação operacional: enquanto não existir kill‑switch físico/remoto independente, o controlo por Wi‑Fi só deve ser usado em testes supervisionados, com o barco preso por corda, potência limitada e distância curta à margem. A perda de ligação Wi‑Fi ou ausência de comandos válidos deve resultar em timeout no ESP32 e paragem dos motores.

A arquitetura de software deve manter a camada de comunicação separada da lógica de controlo. Assim, no futuro, a interface poderá continuar igual mesmo que o meio de comunicação seja substituído por Wi‑Fi externo com antena, rádio/telemetria, 4G/LTE ou outro sistema de maior alcance.

Evolução futura prevista:

Portátil / Telemóvel / Estação em terra
│
│ Wi‑Fi externo com antena / rádio / 4G‑LTE
▼
Raspberry Pi 4
│
│ USB Serial / USB‑C
▼
ESP32
│
├── PWM_ESC_ESQ
└── PWM_ESC_DIR

Nota técnica: o Wi‑Fi interno do Raspberry Pi 4 é adequado para testes próximos, mas não deve ser assumido como solução final de alcance ou segurança. Para antena externa, deverá ser previsto um adaptador Wi‑Fi USB com antena externa ou outro sistema de comunicação dedicado.

### 7.3 Configuração Inicial do Raspberry Pi

Em 2026-07-06 foi iniciada a configuração prática do Raspberry Pi 4, após receção física do módulo. A configuração foi realizada de forma isolada, sem ligação a ESCs, baterias de potência, sensores ou sistema elétrico do barco, reduzindo o risco de dano durante a instalação inicial.

O Raspberry Pi foi preparado para operação headless, isto é, sem monitor, teclado ou rato ligados diretamente. O acesso remoto foi validado por SSH a partir do portátil, confirmando que o Raspberry Pi ficou operacional na rede local.

Sequência de configuração realizada:

1. Preparação de cartão microSD de 32 GB.
2. Instalação do Raspberry Pi OS através do Raspberry Pi Imager.
3. Configuração inicial com hostname sailsafe-pi, utilizador próprio, Wi‑Fi e SSH.
4. Primeiro arranque do Raspberry Pi alimentado por USB‑C a partir de carregador/fonte externa.
5. Acesso remoto confirmado por SSH a partir do portátil.
6. Atualização inicial do sistema com apt update e apt upgrade.
7. Ativação das interfaces I2C e Serial através do raspi-config.
8. Instalação de ferramentas base: Python 3, pip, venv, git, i2c-tools, screen e minicom.
9. Criação da estrutura inicial de pastas do projeto no Raspberry Pi.

Estrutura inicial criada no Raspberry Pi:

~/SAILSAFE/
├── config/
├── logs/
└── software/
└── raspberrypi/

Estado no final da sessão:

O Raspberry Pi encontra-se operacional, acessível por SSH, com interfaces base preparadas para futura integração com sensores I2C e comunicação série/USB com o ESP32. A ligação Raspberry Pi → ESP32 ainda não foi testada nesta sessão e fica definida como próximo passo técnico.

Regra de segurança mantida: não ligar ESCs, motores, baterias de potência ou bus bars antes de validar primeiro a comunicação Raspberry Pi → ESP32 e os mecanismos de failsafe em bancada.

# 8. Lógica de Navegação e Controlo

A lógica futura do Raspberry Pi deverá seguir um ciclo de controlo repetitivo. Em cada ciclo, o sistema lê sensores, calcula o erro de direção e envia comandos de potência diferencial ao ESP32.

1. Ler posição GPS atual

2. Ler velocidade GPS

3. Ler heading/orientação da IMU

4. Obter waypoint atual

5. Calcular distância ao waypoint

6. Calcular rumo desejado

7. Calcular erro de direção

8. Calcular throttle base

9. Calcular correção diferencial

10. Enviar comando ao ESP32: L:<valor> R:<valor>

11. Guardar dados em CSV

12. Repetir em ciclo

A estratégia de controlo diferencial pode ser representada por:

motor_esquerdo = throttle_base - correcao_direcao

motor_direito = throttle_base + correcao_direcao

Os valores iniciais devem ser conservadores: PWM máximo inicial limitado, potência baixa nos primeiros testes em água e correções diferenciais pequenas para evitar instabilidade.

# 9. Arquitetura Mecânica

A configuração catamarã foi escolhida por oferecer boa estabilidade, maior área útil para eletrónica e baterias, distribuição de massa mais favorável e menor tendência para capotar. A disposição física deve reduzir interferências, comprimentos de cabos de potência e risco de entrada de água.

PROA

↑

Antena GPS

│

Raspberry Pi

│

ESP32

│

Bateria(s) / CG

┌───────────┴───────────┐

ESC Esquerdo ESC Direito

│ │

Waterjet Esquerdo Waterjet Direito

↓

POPA

Zona | Componentes principais | Critérios de instalação
Zona superior / caixa estanque | Raspberry Pi, ESP32, GPS, BNO055, ADS1015, Wagos/bornes | Proteção contra água, acesso para manutenção, afastamento de cabos de potência.
Zona inferior / potência | Baterias, fusíveis, bus bars, ESCs | Cabos curtos e grossos, fixação mecânica, ventilação/gestão térmica e isolamento.
Passagem entre caixas | PWM, GND comum, alimentação eletrónica e fios reserva | Usar passa-cabos adequados e strain relief.
Popa | Waterjets e ESCs próximos | Reduzir comprimento de cabos de fase U/V/W e facilitar manutenção.

# 10. Segurança, Failsafe e Procedimentos de Emergência

A segurança é crítica porque o sistema combina água, baterias LiPo, correntes elevadas, motores brushless e software autónomo. O projeto deve adotar uma filosofia fail-safe: qualquer estado duvidoso deve levar à redução de potência ou paragem dos motores.

ID | Situação | Resposta esperada
SAFE-001 | Perda de comunicação Raspberry Pi → ESP32 | ESP32 para os motores após timeout.
SAFE-002 | Comando PWM fora dos limites | ESP32 rejeita comando e coloca motores em stop.
SAFE-003 | GPS inválido ou sem fix | Sistema não inicia navegação autónoma.
SAFE-004 | Bateria baixa | Sistema reduz potência ou regressa/paralisa conforme estratégia futura.
SAFE-005 | Erro de sensor crítico | Entrar em modo manual, HOLD ou estado seguro.
SAFE-006 | Teste em água | Barco deve iniciar preso por corda e com potência limitada.
SAFE-007 | Falha total do sistema (software ou comunicação) | Corte manual imediato de energia através de loop key

### 10.1 Arquitetura de Segurança Temporária — Fase 1

Durante a Fase 1, na ausência de kill-switch físico/remoto independente, o sistema utiliza uma solução de corte manual baseada em conector XT90 (loop key).

Arquitetura:

Bateria → Loop Key → Fusível principal → Distribuição → ESCs

Função:

- A loop key atua como interruptor manual de emergência

- Sem loop key inserida → sistema sem alimentação

- Inserção da loop key → sistema energizado

Limitações:

- Não permite corte remoto

- Requer presença do operador

- Não substitui kill-switch dedicado

Regras operacionais:

- Testes apenas em bancada ou com sistema fisicamente contido

- Potência limitada durante testes iniciais

- Operador sempre junto ao sistema

- Proibido testar em água sem sistema de recuperação (corda)

# 11. Plano de Testes

Os testes devem ser incrementais. Nunca se deve avançar para água com potência real sem validar primeiro comandos, failsafe e paragem imediata.

ID | Teste | Objetivo | Critério de aceitação
TEST-001 | ESP32 isolado | Confirmar programação, Serial e validação de comandos. | Comandos válidos aceites; inválidos provocam stop.
TEST-002 | Failsafe ESP32 | Verificar paragem por perda de comunicação. | Motores ficam em stop após timeout definido.
TEST-003 | 1 ESC sem carga perigosa | Testar resposta PWM de um ESC. | ESC responde a 1000–1150 µs de forma previsível.
TEST-004 | 2 ESCs | Validar controlo independente esquerdo/direito. | PWM_LEFT e PWM_RIGHT controlam ESCs corretos.
TEST-005 | Waterjets em água | Confirmar empuxo e sentido de rotação. | Empuxo correto com potência baixa e pulsos curtos.
TEST-006 | Barco preso em água | Validar estabilidade, paragem e manobra. | Barco responde e para imediatamente quando comandado.
TEST-007 | Raspberry Pi + ESP32 | Comunicação Serial/USB ou UART. | Pi envia comandos e ESP32 executa com segurança.
TEST-008 | GPS | Validar coordenadas e velocidade. | Fix válido e dados consistentes.
TEST-009 | BNO055 | Validar heading e orientação. | Leitura estável e coerente com rotação física.
TEST-010 | Missão waypoint inicial | Teste autónomo limitado. | Barco segue waypoint com velocidade baixa e supervisão.
TEST-011 | Corte manual de energia | Verificar comportamento do sistema ao remover loop key | Motores devem parar imediatamente sem comportamento errático

# 12. Registo Inicial de Riscos

ID | Risco | Prob. | Impacto | Mitigação
RISK-001 | Entrada de água na eletrónica | Média | Alto | Caixa estanque, passa-cabos, teste de vedação, separação potência/eletrónica.
RISK-002 | Falha de ESC ou sobrecorrente | Média | Alto | Fusíveis por ramo, testes progressivos, cabos adequados e inspeção térmica.
RISK-003 | Perda de GPS | Média | Médio/Alto | Não iniciar autonomia sem fix; implementar HOLD/stop em caso de dados inválidos.
RISK-004 | Comando de motor incorreto | Média | Alto | Validação no ESP32, limites de PWM, failsafe e testes em bancada.
RISK-005 | Bateria LiPo mal dimensionada | Média | Alto | Medição de corrente real, alarmes de tensão, fusíveis e procedimentos de carga seguros.
RISK-006 | Instabilidade mecânica/capotamento | Baixa/Média | Alto | Catamarã, centro de gravidade baixo, testes graduais em água calma.
RISK-007 | Perda de comunicação | Média | Alto | Failsafe por timeout; futura telemetria e Return-To-Home.
RISK-008 | Interferência elétrica nos sensores | Média | Médio | Separar cabos de potência e sinal; GND comum bem planeado; cabos curtos e organizados.
RISK-009 | Corte de energia sob carga | Média | Alto | Possível comportamento imprevisível dos ESCs ao remover alimentação; mitigar com testes progressivos e potência limitada

# 13. Lista Inicial de Componentes (BOM)

Categoria | Componente | Quantidade | Estado / Observações
Computação | Raspberry Pi 4 2GB | 1 | Computador de bordo para navegação e logging.
Controlo | ESP32 DevKit | 1 | Controlador de motores e failsafe; já testado em programação e Serial.
Propulsão | ESC brushless | 2 | Um por waterjet; modelo final a confirmar.
Propulsão | Waterjet brushless | 2 | Propulsão diferencial; modelo final a confirmar.
Sensores | GPS NEO-8M com antena ativa | 1 | Módulo completo necessário; não apenas antena.
Sensores | BNO055 | 1 | IMU/orientação por I2C.
Sensores | ADS1015 | 1 | ADC externo ADS1015 de 12-bit por I2C; módulo completo necessário.
Energia | LiPo 3S 11,1 V 5000 mAh | 1 | Bateria prevista; função final a confirmar.
Energia | LiPo 3S 11,1 V 2200 mAh | 1 | Bateria prevista; função final a confirmar.
Energia | Conversor DC‑DC 5 V | 1 | Alimentação da eletrónica.
Proteção | Fusíveis | Vários | Principal, ESCs e eletrónica.
Distribuição | Bus bars | 2 | Positivo e negativo da potência.
Cablagem | Wagos/bornes | Vários | Apenas baixa corrente/sinais.
Estrutura | Caixa estanque | 1+ | Proteção de eletrónica e/ou potência.
Segurança | Loop key XT90-S (anti-spark) + fêmea | 2 | Corte manual por casco; um polo (positivo).
Segurança | Relé 60–70 A | 2 | Corte remoto no positivo; acima do fusível.
Segurança | Módulo RC-switch (servo→relé) | 2 | Um por casco, mantendo os cascos isolados.
Comunicação | Recetor de rádio com saídas PWM + série | 1 | Canal PWM para o kill; série para waypoints.
Comunicação | Emissor de rádio | 1 | Manípulo físico de duas posições para o kill.
Sensores | Sensor de corrente ACS758-050U | 1 | Um casco por agora; Hall isolado, 60 mV/A.

# 14. Organização Documental Recomendada

Para o projeto ser reconhecido como projeto de engenharia, a documentação deve ser organizada de forma consistente. A estrutura abaixo pode ser usada localmente e futuramente num repositório GitHub.

SAILSAFE/

│

├── 00_Project_Management/

│ ├── Objectives.pdf

│ ├── Requirements.pdf

│ ├── Timeline.pdf

│ └── Budget.xlsx

│

├── 01_Mechanical/

│ ├── CAD/

│ ├── Hull_Design/

│ ├── Assembly_Drawings/

│ └── STL_Files/

│

├── 02_Electrical/

│ ├── Schematics/

│ ├── Power_System/

│ ├── Wiring_Diagrams/

│ └── PCB/

│

├── 03_Software/

│ ├── RaspberryPi/

│ └── ESP32/

│

├── 04_Simulations/

│ ├── Navigation/

│ ├── Dynamics/

│ └── Control/

│

└── 05_Documentation/

├── Weekly_Reports/

├── Photos/

├── Videos/

├── Test_Results/

└── Final_Report/

# 15. Documentos Derivados Recomendados

Documento | Objetivo | Prioridade
SAILSAFE_Electrical_Architecture_v1 | Detalhar esquema elétrico, fusíveis, cablagem, conectores, bus bars e GND comum. | Alta
SAILSAFE_Test_Plan_v1 | Formalizar testes de bancada, água, failsafe, sensores e autonomia. | Alta
SAILSAFE_Software_Architecture_v1 | Detalhar módulos Python/Raspberry Pi e firmware ESP32. | Alta
SAILSAFE_Risk_Register_v1 | Manter riscos, causas, mitigação e estado. | Média/Alta
SAILSAFE_Mechanical_Architecture_v1 | Detalhar casco, caixas, montagem, distribuição de massa e estanquidade. | Média
SAILSAFE_Engineering_Logbook_v1 | Registar decisões, problemas, testes e resultados semanalmente. | Alta

# 16. Próximos Passos Imediatos

1. Congelar e documentar o protocolo atual de comando entre Raspberry Pi e ESP32 no formato textual em percentagem.
2. Manter a validação da cadeia Raspberry Pi → ESP32 como prioridade antes de qualquer teste com ESCs, motores ou baterias de potência.
3. Consolidar o script Python de keep-alive/command streaming no Raspberry Pi, com envio periódico inferior ao timeout do failsafe.
4. Formalizar a máquina de estados mínima do ESP32: comando válido, stop, comando inválido e failsafe.
5. Atualizar a documentação técnica para refletir a implementação atual do firmware (percentagem em vez de interface 1000–1150 μs ao nível do protocolo de aplicação).
6. Só avançar para testes com 1 ESC após a cadeia de comunicação, paragem segura e comportamento de timeout estarem estáveis e repetíveis em bancada.
7. Só avançar para autonomia por waypoints após controlo manual, failsafe, sensores e logging estarem validados.

### 16.1 Próximos Passos após Configuração Inicial do Raspberry Pi

Após a validação inicial da comunicação USB entre Raspberry Pi 4 e ESP32, os próximos passos técnicos passam a concentrar-se na consolidação do emissor periódico no Raspberry Pi e na estabilização do parser UART do ESP32, ainda sem ligação a ESCs, motores ou baterias de potência.

1. Manter apenas o ESP32 ligado ao Raspberry Pi por USB durante a validação atual.
2. Confirmar funcionamento repetível em /dev/ttyUSB0 com bridge CH341.
3. Validar o parser UART não bloqueante com newline como delimitador de comando.
4. Usar script Python dedicado no Raspberry Pi para envio periódico (keep-alive) e STOP na saída.
5. Confirmar experimentalmente que o failsafe não dispara enquanto o keep-alive corre e que dispara quando o envio pára.
6. Só depois avançar para um emissor dinâmico com throttle + steering.
7. Integrar sensores I2C e GPS apenas após a camada de comando periódico estar estável.
8. Preparar plano de teste específico para 1 ESC, ainda sem montar os waterjets no barco.
9. Não realizar testes com potência real antes de validar failsafe, paragem e limites de PWM/percentagem.

# Apêndice A — Glossário

Termo | Significado
ESC | Electronic Speed Controller; controlador eletrónico de velocidade para motores brushless.
Waterjet | Sistema de propulsão que gera empuxo através de jato de água.
PWM | Pulse Width Modulation; sinal usado para comandar ESCs.
I2C | Barramento de comunicação de dois fios, SDA e SCL.
UART | Comunicação série assíncrona por TX/RX.
Failsafe | Mecanismo que coloca o sistema em estado seguro perante falhas.
GND comum | Referência elétrica comum entre eletrónica, sinais e potência.
Waypoint | Ponto GPS usado como objetivo de navegação.

# Apêndice B — Decisões Técnicas em Aberto

ID | Decisão | Estado
OPEN-001 | Modelo exato dos ESCs | Fechado — ESC 40 A, compatível com motor 2440 KV4500
OPEN-002 | Modelo final dos waterjets | A definir
OPEN-003 | Função final de cada bateria | Fechado — 3S 5000 mAh por casco para propulsão; 3S 2200 mAh para eletrónica, esta última confirmada fisicamente e monitorizada por ADC.
OPEN-004 | Comunicação Raspberry Pi ↔ ESP32 por USB ou UART | Fechado — USB-C / USB Serial validado em bancada; dispositivo detetado como /dev/ttyUSB0 (CH341)
OPEN-005 | Ligação final do GPS se UART estiver ocupada | Fechado — UART do GPIO em /dev/serial0 a 9600 8N1, com o TX do módulo em GPIO15 e o RX em GPIO14. A UART ficou livre quando o ESP32 passou para USB (OPEN-004), e usá-la evita um segundo /dev/ttyUSB* a disputar nome com o ESP32. No Pi 4 exige dtoverlay=disable-bt para que serial0 seja a PL011 e não a mini-UART, cujo baud varia com o relógio do core.
OPEN-006 | Estratégia de Return-To-Home | Fechado na parte do ponto; trajeto assumido como limitação da Fase 1. O gatilho é a tensão da bateria da eletrónica. O ponto de regresso é a posição registada uma única vez no instante do ARM, a partir da média de fixes validados, e nunca reescrita durante a missão. O trajeto é linha reta até esse ponto, admissível apenas em plano de água aberto e à vista, por não haver deteção de obstáculos na Fase 1. Ver secção 22.3.
OPEN-007 | Telemetria em tempo real | Futura — e dependente de OPEN-011. O registo de bordo existe (CSV por sessão); o que não existe é ligação de retorno, protocolo ou estação em terra. A escolha do rádio decide o custo: com ELRS/CRSF a telemetria vem no mesmo link que faz o corte, com FlySky iA6B fica limitada aos sensores de iBus. Ver secção 22.4.
OPEN-008 | Kill‑switch físico/remoto independente do software | Fechado — relé no positivo de cada casco (60–70 A, acima do fusível), bobina alimentada pela bateria do próprio casco, comandada por módulo RC-switch a partir de um canal PWM do recetor. O caminho de corte não passa pelo Raspberry Pi nem pelo ESP32. Loop keys XT90-S mantidas como corte manual.
OPEN-009 | Formato de comando atual Pi → ESP32 | Fechado provisoriamente — texto em percentagem no formato L:10 R:10 com newline, keep-alive periódico e failsafe por timeout no ESP32
OPEN-010 | Comportamento do ESC ao perder sinal (pára ou mantém o último valor) | A confirmar na ficha antes da compra — determina se um corte ao nível do sinal seria sequer admissível.
OPEN-011 | Sistema de rádio final | Em aberto — FlySky FS-i6X + iA6B (PWM + iBus, ~60 €) por orçamento, ou ELRS (ER6, 29,90 €) por alcance.
OPEN-012 | Segundo ADS1015 para instrumentar o casco direito | Adiado — endereço I2C alternativo pelo pino ADDR permite acrescentar sem alterar cablagem nem código.
OPEN-013 | Cerca virtual (geofence) do plano de água | Em aberto — proteção contra encalhe por polígono carregado antes da saída, com semântica de guarda (veta, não conduz) e margem dimensionada pela dispersão medida do GPS. Fase 2, depois do kill-switch remoto (OPEN-011). Ver secção 22.11.

# 17. Atualização de Arquitetura Mecânica e Elétrica — v1.5

Esta secção consolida as decisões preliminares tomadas em 2026-07-11 para a construção do primeiro protótipo. As dimensões e quantidades permanecem sujeitas a confirmação através da medição física e pesagem dos componentes antes do corte definitivo.

## 17.1 Conceito estrutural do protótipo

O protótipo deverá utilizar dois cascos com núcleo em XPS de célula fechada, revestidos com tecido de fibra de vidro e resina epóxi. O XPS fornece forma e volume de flutuação; a pele laminada fornece rigidez, resistência superficial e impermeabilização.

O XPS não deve receber diretamente parafusos ou cargas concentradas. Devem ser integrados reforços em contraplacado nas popas, nas ligações das travessas, na base da caixa central e no ponto estrutural usado pela linha de recuperação.

Dimensões preliminares: 800 mm de comprimento total, 350 mm de largura total, cascos com 100–110 mm de largura e 130–140 mm de altura. A proa deverá ser inclinada ou facetada para reduzir a resistência à água.

A união entre cascos deverá recorrer a três travessas estruturais: frontal, central e traseira. As travessas devem ligar-se a insertos ou blocos reforçados, e não apenas à pele fina de fibra ou ao XPS.

## 17.2 Compartimentos e distribuição de massa

A bateria de propulsão e a bateria de eletrónica devem permanecer mecanicamente fixas, acessíveis e instaladas o mais baixo possível. A caixa de eletrónica deve ser fisicamente separada da zona de maior corrente, mantendo acesso para manutenção.

A massa prevista de 6,0–6,5 kg (v1.8) resulta dos volumes do modelo v4 corrigidos e de densidades típicas, não de pesagem; a meta otimizada de 5,0–5,5 kg exige aligeiramento estrutural deliberado. Todos os componentes devem ser pesados e dispostos à escala real antes do corte definitivo. O centro de gravidade deve ser ajustado através da posição das baterias.

Os ESCs devem ser instalados próximos dos respetivos waterjets, protegidos contra salpicos, acessíveis e com gestão térmica. Não devem ser encapsulados permanentemente em XPS ou epóxi.

## 17.3 Waterjets e reforço da popa

Cada waterjet deve ser fixado a uma placa de contraplacado de aproximadamente 6–10 mm integrada na popa e laminada à estrutura. Os parafusos não devem apertar diretamente contra XPS.

Os furos devem ser selados com epóxi antes da montagem final. A fixação deve usar parafusos adequados, anilhas largas ou placa de distribuição de carga, porcas quando aplicável e vedação compatível com o sistema de materiais.

A geometria da entrada de água, a altura do waterjet, a linha de água e o acesso aos parafusos devem ser confirmados com o componente real antes de cortar a popa.

## 17.4 Encaminhamento de cabos

Os cabos podem atravessar as travessas dentro de tubo ou conduíte substituível. Depois da saída da travessa, podem seguir pela face superior e interior de cada casco, desde que estejam protegidos, fixos, afastados da admissão dos waterjets e dotados de alívio de tração.

Os três cabos de fase entre ESC e motor devem ser mantidos curtos. Para cada ESC localizado junto do motor, a alimentação deve ser transportada desde a distribuição central por dois cabos de potência, positivo e negativo, acompanhados pelo sinal PWM e respetivo GND.

As entradas em caixas devem usar passa-cabos adequados e uma geometria que evite que a água escorra diretamente para o interior.

## 17.5 Secções de cabos

O cabo de 6 mm² fica reservado para a bateria de potência, fusível principal, barramentos, fusíveis individuais e alimentação positiva e negativa de cada ESC.

O cabo de 1,5 mm² destina-se à alimentação da eletrónica, entrada do conversor DC-DC e ligação única de referência entre o GND da eletrónica e o barramento negativo de potência.

O cabo de 0,75 mm², ou os fios originais dos módulos quando adequados, destina-se a PWM, GND de sinal, I2C, UART e outros sinais de baixa corrente.

Os Wagos ficam limitados a baixa corrente e sinais. Não devem integrar o caminho principal de corrente dos motores.

## 17.6 Duas baterias e GND comum

A LiPo 3S de 5000 mAh permanece dedicada à propulsão. A LiPo 3S de 2200 mAh permanece dedicada à eletrónica através do conversor DC-DC de 5 V.

Os positivos das duas baterias devem permanecer separados. As baterias não devem ser colocadas em paralelo.

O negativo da bateria de 5000 mAh liga ao barramento negativo de potência. O negativo da bateria de 2200 mAh liga ao ponto GND da eletrónica. Deve existir uma única ligação de referência, em estrela, entre o GND da eletrónica e o barramento negativo de potência.

Os fios GND que acompanham os sinais PWM devem continuar ligados ao GND do ESP32. Contudo, esses fios finos não devem constituir a única ligação intencional entre os negativos dos dois subsistemas.

Se os ESCs disponibilizarem saída BEC de 5 V através de fio vermelho, essa saída deve permanecer isolada enquanto a eletrónica for alimentada pelo conversor DC-DC dedicado, salvo validação específica do modelo do ESC.

## 17.7 Sequência de validação mecânica

9. 1. Medir e pesar todos os componentes.
10. 2. Fazer uma disposição à escala real em cartão.
11. 3. Confirmar centro de gravidade, acesso e remoção de componentes.
12. 4. Construir e laminar amostras pequenas de XPS antes dos cascos.
13. 5. Verificar compatibilidade do epóxi, primer e tinta com o XPS.
14. 6. Construir os cascos e realizar teste de estanquidade sem eletrónica.
15. 7. Ensaiar os cascos com pesos equivalentes à massa final.
16. 8. Integrar um ramo de propulsão de cada vez.
17. 9. Realizar os primeiros testes na água com linha de recuperação, potência limitada e supervisão direta.

## 17.8 Materiais preliminares para a estrutura

Previsão inicial: aproximadamente 1,2 m² úteis de XPS de 30–50 mm, 5–6 m² de tecido de fibra de vidro de 160–200 g/m², cerca de 10 m de fita de fibra, 2,5–3 kg de sistema epóxi de laminação, carga espessante e retalhos de contraplacado de 6–10 mm para reforços.

As quantidades devem ser revistas depois de fechar a geometria real dos cascos e realizar uma amostra de laminação. A disponibilidade e compatibilidade dos materiais devem ser confirmadas antes da compra.

## 17.9 Decisões ainda em aberto

- Modelo exato, impermeabilização e refrigeração dos ESCs.
- Geometria final dos cascos e detalhe das travessas.
- Tipo exato de epóxi, tecido e acabamento compatível com XPS.
- Posição final das baterias após pesagem e ensaio de flutuação.
- Valor final dos fusíveis por ramo após medição de corrente.
- Implementação do kill-switch físico/remoto antes de operação sem corda.

# 18. Atualização de Arquitetura Mecânica e de Encapsulamento — v1.7

## 18.1 Construção dos cascos

Os cascos mantêm o núcleo em XPS de célula fechada, mas a pele estrutural passa de laminação integral em fibra de vidro para uma pele híbrida: contraplacado de 3 mm colado nas zonas planas (faces laterais, fundo, convés e popa, na zona prismática X 200–800 mm) e laminação em fibra de vidro + epóxi na proa (X 0–200 mm), onde a medição do modelo confirmou uma cunha tridimensional — a largura afunila de 109 mm para ≈3 mm em planta, além dos chanfros de perfil — sobre a qual contraplacado plano não assenta sem facetagem (cola PU à prova de água ou epóxi; resinas de poliéster e colas com solvente são proibidas por dissolverem o XPS). As arestas e o fundo recebem fita de fibra de vidro com epóxi, e toda a madeira exterior é selada com epóxi. Esta alteração troca ≈0,85 kg de massa adicional por uma redução substancial de tempo e risco de execução, aproveitando as três placas de contraplacado de 3 mm já adquiridas.

É adicionada uma longarina de 20×10 mm embutida ao longo do convés de cada casco, colada em rasgo no XPS, servindo de ponto de aparafusamento das travessas em madeira em vez de espuma. Não é adicionada qualquer outra estrutura interna: o sanduíche pele + núcleo cumpre a função estrutural.

## 18.2 Encapsulamento da eletrónica

A caixa de eletrónica em contraplacado é substituída por uma caixa comercial IP66 de 204×155×100 mm com tampa articulada, instalada sobre a tampa da caixa de baterias. A caixa de baterias utiliza contraplacado de 3 mm com ripas e reforços locais, conforme definido na secção 18.4.

- Todas as entradas de cabos na caixa IP66 são feitas por bucins (prensa-estopas PG7/PG9); furos sem bucim anulam a classificação IP.
- Cada cabo forma um laço de gotejamento imediatamente antes da entrada na caixa.
- A antena ativa do GPS é instalada no exterior, no topo da caixa, com o respetivo furo vedado.

## 18.3 Encaminhamento de cabos até aos ESCs

Os cabos entre a caixa central e cada ESC seguem em conduíte corrugado de 16 mm, fixado com abraçadeiras ao longo da travessa traseira (T3), terminando junto de cada cobertura de ESC. Cabos de potência de 6 mm² e fios de sinal PWM podem partilhar o conduíte, mantendo separação nas pontas e folga de serviço. Cabos soltos no convés são proibidos pelos modos de falha já identificados a 2026-07-11: abrasão, condução de água e ingestão pela admissão dos waterjets.

## 18.4 Caixa de baterias em contraplacado de 3 mm e segurança LiPo

A caixa de baterias passa de contraplacado de 9 mm para contraplacado de 3 mm com ripas de reforço (cantos verticais em ripa de 8×8 a 10×10 mm; duas ripas no fundo; duas ripas na face inferior da tampa alinhadas com os pontos de fixação da caixa IP66), reduzindo a massa de ≈0,63 kg para ≈0,30 kg. As cotas dos painéis dependem da espessura das paredes (extremo = 180 − 2×espessura): laterais 230×81, extremos 174×81, fundo 224×174, tampa 230×180. Parafusos apenas em zonas com reforço local (dupla camada de 3 mm, anilhas largas ou insertos); o fundo apoia na placa base do barco.

- A caixa de baterias não deve ser hermética: em caso de falha de uma célula LiPo há libertação de gases, e a saída de cabos (furo com passa-fios de borracha e laço de gotejamento, sem vedação a silicone) funciona como respiro.
- O carregamento das baterias é sempre efetuado fora do barco e da caixa, em saco ou superfície ignífuga.
- O porta-fusível principal permanece acessível sem desmontar a retenção das baterias (espuma no fundo, batentes e uma cinta de velcro por bateria, sobre zonas reforçadas).
- Critério de aceitação: caixa esquadrejada, sem flexão preocupante do fundo ou da tampa com a caixa IP66 montada, baterias imobilizadas, madeira e topos selados com epóxi, caixa removível para manutenção.

# 19. Atualização da Alimentação do Raspberry Pi — v1.9

## 19.1 Integração física da alimentação

O Raspberry Pi 4 é alimentado pelo conversor DC-DC através do conector GPIO. O positivo de 5 V é distribuído pelos pinos físicos 2 e 4 e o GND pelos pinos físicos 6 e 14. Os dois contactos por polaridade repartem a corrente e melhoram a robustez da ligação.

Os cabos foram soldados aos pinos do Raspberry Pi e receberam isolamento e alívio de tensão. Foi instalado um condensador eletrolítico de 470–1000 µF, com tensão nominal mínima de 10 V, junto ao ponto de entrega dos 5 V, para apoiar a estabilidade perante picos de corrente.

A entrada USB-C fica reservada para configuração e diagnóstico. É proibida a alimentação simultânea pela entrada USB-C e pelos pinos GPIO, evitando colocar duas fontes diretamente sobre a mesma linha de 5 V.

## 19.2 Procedimento de validação

18. Arrancar inicialmente o Raspberry Pi apenas por USB-C, sem ESP32, sensores ou ESCs ligados, e confirmar o acesso por SSH.
19. Encerrar o sistema com sudo poweroff e aguardar o fim da atividade do cartão microSD antes de remover o USB-C.
20. Confirmar que o USB-C está completamente desligado e arrancar exclusivamente através da bateria de eletrónica e do conversor DC-DC.
21. Executar vcgencmd get_throttled. O critério inicial de aceitação é throttled=0x0.
22. Executar uptime e consultar dmesg para detetar avisos de under-voltage, voltage ou throttling.
23. Manter o Raspberry Pi em funcionamento durante 10–15 minutos, repetir as verificações e só depois ligar o ESP32 por USB.

## 19.3 Incidente do cartão microSD

Durante o primeiro ensaio da alimentação pelos pinos GPIO, a alimentação foi interrompida antes de o sistema concluir o arranque e sem um encerramento controlado. Após o corte, o Raspberry Pi deixou de ficar acessível por SSH e não apareceu de forma fiável na rede local.

O cartão microSD continuou fisicamente detetável no computador e a partição bootfs de arranque permaneceu acessível. O diagnóstico aponta para corrupção lógica de ficheiros ou perda da configuração do Raspberry Pi OS, e não para destruição física do cartão ou dano elétrico confirmado no Raspberry Pi.

O Raspberry Pi OS foi regravado através do Raspberry Pi Imager, com reposição do hostname sailsafe-pi, utilizador, Wi-Fi e SSH. O acesso remoto voltou a ficar disponível quando o Raspberry Pi foi alimentado por USB-C.

## 19.4 Regras operacionais de proteção do sistema

- Não interromper deliberadamente a alimentação durante o arranque ou durante atividade intensa do LED ACT.
- Utilizar sudo poweroff antes de cortar a alimentação sempre que existir acesso ao sistema.
- Não interpretar apenas os LEDs como validação elétrica: o LED vermelho confirma presença de alimentação e o LED verde indica atividade do armazenamento, mas a aceitação depende também de vcgencmd get_throttled e dos registos do sistema.
- Manter cópias de segurança da configuração e do software do projeto no repositório GitHub, permitindo regravar o sistema sem perder trabalho.
- Considerar numa evolução futura um circuito de shutdown controlado ou reserva de energia suficiente para concluir o encerramento após deteção de perda da alimentação principal.

# 20. Atualização de Arquitetura Mecânica, Software e Segurança — v1.11

## 20.1 Arquitetura mecânica v6.1 — baterias nos cascos

A revisão v6/v6.1 (blueprint madeira v6.1, 5 folhas) transfere as baterias de propulsão para alojamentos dentro dos cascos e elimina a placa base e a caixa central de baterias, reduzindo o centro de gravidade de ≈142 mm para ≈107 mm sem lastro. Elementos principais:

- Alojamentos das baterias nos cascos: centro X=341, Y=±123, fundo a z=45 (≈6 mm acima da linha de água WL=39); forro interior em contraplacado de 3 mm selado com epóxi (o LiPo nunca contacta o XPS).
- Escotilhas de serviço 185×85 no convés, com reforço perimetral (2.ª camada, abertura útil 155×55), 6 insertos roscados M4 de latão por escotilha, parafusos de orelhas M4 em nylon, junta de neopreno de 3 mm colada à tampa e respiro por 2 entalhes de 2 mm no rebordo (compartimento não hermético, regra 18.4).
- Caixa IP66 204×155 pousada ao nível do convés (fundo z=152, topo z=252, centro X=354), sobre 4 calços colados e retida por 2 ripas aparafusadas às faces de T1/T2. Correção v6 validada em 3D: o túnel entre cascos (118 mm) é mais estreito do que a caixa (155 mm), pelo que a caixa não pode descer abaixo do convés.
- Travessas T1/T2/T3 (350×45×40) com centros em X = 222,5 / 485 / 663 — T2 recolocada em X=485 para receber os alojamentos e a caixa IP66 no vão T1–T2 (217,5 mm).
- Pele em contraplacado marítimo de 3 mm nas zonas planas; proa (X 0–200, cunha 3D) laminada em fibra de vidro 200 g/m² + epóxi (2 camadas); transom inserts em contraplacado de 9–10 mm; lista de materiais consolidada na folha 5 do blueprint.

Sequência de serviço das baterias: retirar as 2 chaves → abrir escotilhas → retirar as baterias pela patilha de webbing → carregar fora do barco. Montagem: bateria + cabos → fechar tampas (aperto manual em cruz) → ligar eletrónica → aguardar neutro do ESP32 → inserir chaves.

## 20.2 Estado do software (validado em bancada/simulação)

O software do Raspberry Pi está organizado em packages (communication, control, telemetry, tests) com o main.py como orquestrador. Estado em 2026-07-23:

- SerialLink (communication): ligação série robusta ao ESP32 — tolera ESP32 ausente, buffer de linhas completas, descarte do lixo de arranque, STOP garantido no fecho.
- Máquina de estados DISARMED ↔ ARMED / NAV: arranque sempre em DISARMED; ARMED com heartbeat 0/0 a 5 Hz; STOP com prioridade absoluta; perda/regresso da ligação série nunca rearma sozinho. Timeout do failsafe do ESP32 medido em ≈1,1 s (heartbeat de 200 ms dá margem confortável).
- Heading hold (control/heading.py): normalização do erro angular para (−180°, 180°] e controlador proporcional com saturação; mixer throttle+steer → L/R com teto de 30% alinhado com o PERCENT_MAX_SAFE do firmware.
- Navegação por waypoints (control/navigation.py): haversine, bearing e WaypointNav com raio de chegada; validada em ciclo fechado sintético (SimulatedBoat) no PC e no Pi.
- Logging (telemetry/logger.py): um CSV por sessão com timestamp ao milissegundo e flush imediato; eventos BOOT/SERIAL/STATE/TX/RX/STOP/HEADING/SHUTDOWN.
- Testes automáticos sem hardware (tests/): heading, mixer e navegação; modo NAV validado com o ESP32 real a aceitar os comandos (malha fechada pelo simulador, sem motores).

Fluxo de desenvolvimento: edição no PC → commit/push → git pull no Raspberry Pi; GitHub como fonte de verdade; branch main como principal. Repositório público com licença MIT e aviso de segurança.

## 20.3 Kill-switch remoto — definição do caminho

Avaliada e descartada a utilização de uma antena DVB (ex.: TW25): trata-se de uma antena de receção de televisão (banda UHF de broadcast), sem capacidade de transmissão nem função de corte. O kill-switch remoto exige um link de rádio com comando ou heartbeat cuja perda dispara o failsafe, mais a eletrónica de corte de potência. Opções em avaliação:

- Sistema RC de hobby a 2,4 GHz (ex.: ELRS): emissor no operador, recetor no barco, canal dedicado a acionar o corte de alta corrente; failsafe do recetor corta a potência na perda de sinal. Solução mais simples e desenhada para o efeito.
- Link LoRa (433/868 MHz) com heartbeat: maior alcance, mas exige desenvolver a lógica de failsafe; a antena tem de corresponder à banda do rádio.

Até existir o corte remoto, mantêm-se as loop keys XT90 por ramo de propulsão como corte manual (secção 10.1) e a proibição de testes sem corda, potência limitada e supervisão direta.

## 20.4 Estratégia de dados

- A bordo: escrita sequencial (CSV ou registos binários de tamanho fixo) alimentada por um buffer circular em array estático; sem base de dados e sem alocação dinâmica no ciclo de tempo real; flush regular para sobreviver a cortes de energia.
- Em terra: análise das sessões com SQLite (ficheiro único, sem servidor) para consultas sobre logs e, futuramente, metadados de vídeo sincronizados por timestamp.
- Previsão de eficiência/autonomia: modelo físico de energia + regressão sobre os logs, dependente da medição real de corrente e tensão (ADS1015 + sensor de corrente); descartado o uso de LLM para esta função.

# 21. Atualização de Segurança, Sense e Software — v1.12

## 21.1 Kill-switch remoto — arquitetura fechada

Esta secção fecha OPEN-008. O corte remoto é feito por relé na linha positiva de cada casco, instalado a jusante do fusível e da loop key, e comandado por um canal de rádio que não atravessa software do projeto.

- Corte no POSITIVO, nunca no negativo. O negativo de cada casco é a referência de massa e o seu único caminho até à massa da eletrónica é o fio preto da ficha servo do ESC; cortá-lo obrigaria a corrente de retorno a procurar caminho por esse fio, dimensionado para miliamperes.
- Hierarquia de proteção: fusível (40–50 A) < relé (60–70 A) < cabo (6 mm²). O fusível tem de ser o elo mais fraco, por ser o único componente desenhado para falhar de forma controlada.
- Bobina de cada relé alimentada pela bateria do próprio casco, a montante dos contactos. Alimentá-las pela bateria da eletrónica custaria cerca de 35 % da autonomia desta (1,9 h → 1,3 h); pela bateria do casco custa 4–6 % por missão.
- Um módulo RC-switch por casco (dois no total), para que a corrente das bobinas não atravesse a ponte pela massa da eletrónica e para não criar um ponto único de falha a comandar os dois cascos. Um único canal do recetor comanda ambos os módulos.
- O canal do kill sai do recetor em PWM por hardware e vai direto ao módulo, sem passar pelo Raspberry Pi nem pelo ESP32. A razão é concreta: o PWM do ESP32 é gerado pelo periférico LEDC, em hardware, e se o firmware encravar (sem reiniciar) o sinal mantém-se com o último valor, sem que o failsafe de software chegue a correr.
- Failsafe do recetor configurado por canal para abrir o relé na perda de link. Recetores que mantenham o último valor não são admissíveis nesta função.
- As loop keys XT90-S mantêm-se e não são substituíveis pelo corte remoto: respondem a perguntas diferentes — a chave garante que é seguro pôr as mãos junto aos jatos, o rádio garante que o barco pára à distância.

Efeito colateral favorável da arquitetura de três circuitos: o corte remoto atua apenas sobre a propulsão e deixa a eletrónica viva, preservando rádio, registo e capacidade de rearmar. Numa arquitetura de bateria única, cortar a propulsão apagaria o registo precisamente no instante que interessa analisar.

## 21.2 Baterias, autonomia e regresso

A bateria da eletrónica foi confirmada fisicamente como LiPo 3S 2200 mAh. O esquema elétrico v1.11 indica 2S 2200 mAh e está errado; a correção do esquema fica pendente. As secções 5.2 e 17.6 deste documento já indicavam 3S e permanecem válidas.

- Energia útil estimada: 19,5 Wh (80 % de 24,4 Wh). Com o consumo estimado de 7,2 W já incluindo o recetor de rádio, resulta em cerca de 2,7 h.
- Descoberta principal: as duas baterias esgotam-se em relógios diferentes. A da eletrónica consome-se com o tempo decorrido, independentemente de o barco andar; as de propulsão consomem-se apenas enquanto há impulso. Em qualquer cenário de utilização com paragens, deriva ou navegação lenta, a bateria da eletrónica esgota-se primeiro.
- É também a falha mais grave das duas: ao esgotar-se, perdem-se rádio, registo e controlo em simultâneo, e o barco fica à deriva sem posição conhecida. O esgotamento da propulsão deixa o barco parado mas localizável.
- Consequência de arquitetura: a bateria da eletrónica passa a ser monitorizada por ADC e a servir de gatilho de regresso. O barco aborta a missão e regressa abaixo de um limiar, sem depender de o operador reparar a tempo nem de o link estar disponível. Fecha parcialmente OPEN-006.
- Esta decisão é também o que torna aceitável alimentar o recetor de rádio pela bateria da eletrónica: se esta morrer, os relés abrem e a propulsão é cortada — comportamento seguro, mas evitável pelo regresso antecipado.

## 21.3 Sense — atribuição de canais e divisores

O ADS1015 tem quatro entradas. A atribuição foi revista tendo em conta que um divisor resistivo custa cêntimos e um sensor de corrente custa euros: o recurso escasso é o canal, não o componente.

- A0 — tensão do casco esquerdo (divisor). A1 — tensão do casco direito (divisor). A2 — tensão da bateria da eletrónica (divisor). A3 — corrente do casco esquerdo (ACS758-050U).
- Instrumentar apenas um casco é aceitável para o modelo de energia. O desequilíbrio entre cascos foi medido em simulação: 0,0 % em linha reta, −1,6 % em ziguezague, +8,9 % na missão de demonstração e +13,6 % num percurso quadrado com todas as viragens para o mesmo lado. Medir um casco e duplicar dá um erro de cerca de 7 % no total, abaixo da incerteza atual da potência dos motores.
- Limitação aceite: um jato obstruído no casco não instrumentado não é detetado diretamente. A queda de tensão sob carga serve de indicador indireto, calibrando no casco instrumentado a relação entre queda e corrente.
- Divisores de 5 kΩ (superior) e 1 kΩ (inferior), k = 0,1667, aproveitando resistores já disponíveis. Uma bateria 3S carregada (12,6 V) dá 2,100 V à entrada, com fundo de escala de 24,6 V no PGA de ±4,096 V.
- O condensador de filtro passa a 2,2 µF (e não 1 µF como na v1.11.1), porque a impedância de fonte baixou de 1,80 kΩ para 833 Ω; mantém-se o corte a cerca de 88 Hz.
- A calibração de um ponto por canal continua obrigatória: o erro dominante é a tolerância dos resistores, não a resolução do conversor.
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

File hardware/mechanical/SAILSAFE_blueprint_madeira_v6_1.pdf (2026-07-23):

VISTA DE TOPO | vão T1 T2 = 217,5 recebe alojamentos e caixa IP66

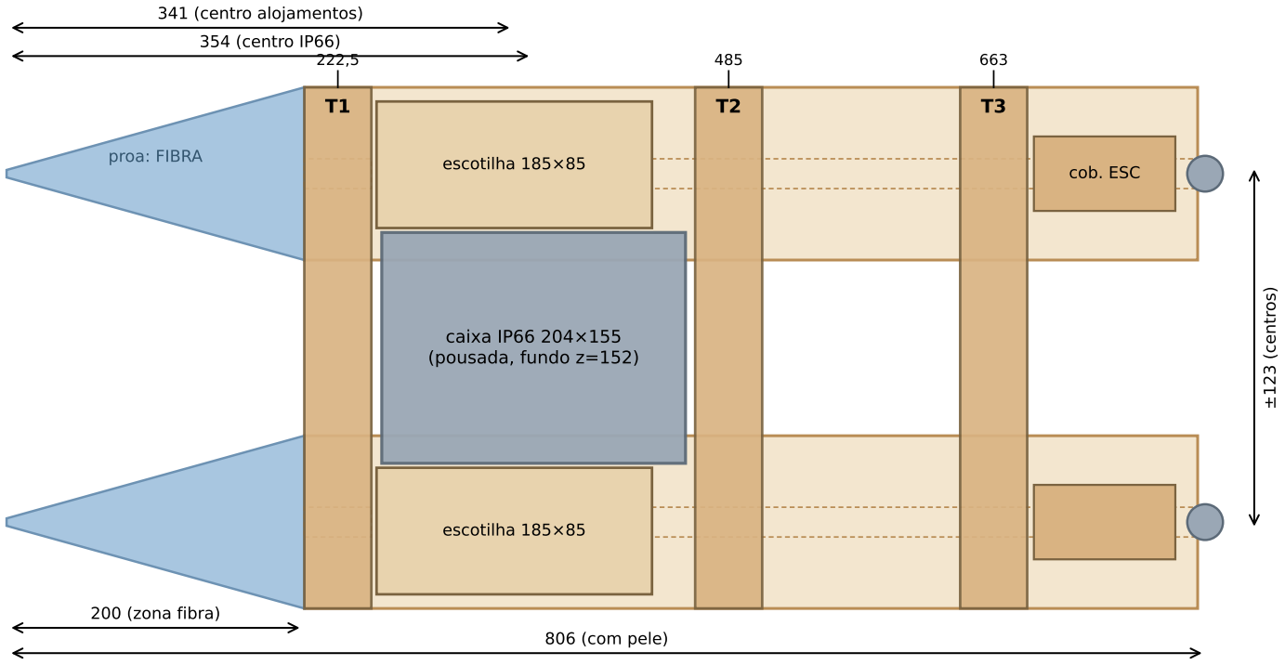
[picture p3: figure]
caixa IP66 204×155 (pousada, fundo z=152); escotilha 185×85; cob. ESC; proa: FIBRA; 806 (com pele); 200 (zona fibra); 341 (centro alojamentos); 354 (centro IP66); ±123 (centros)

VISTA LATERAL | bateria por casco (fundo do alojamento a z=45, | 6 acima da WL)
SAILSAFE v6.1 | Blueprint madeira (folha 1/5): vistas de conjunto | arquitetura v1.11
cotas em mm · alterações v6: T2 | X=485; alojamentos das baterias nos cascos (X=341, Y=±123, fundo z=45); caixa IP66 pousada ao nível do convés (fundo z=152) | o túnel entre cascos (118) é mais estreito do que a caixa (155)

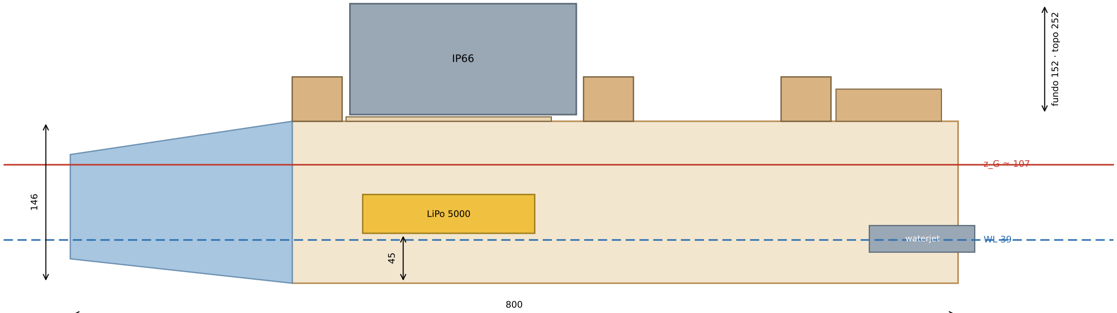
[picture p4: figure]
LiPo 5000; waterjet; fundo 152 · topo 252
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

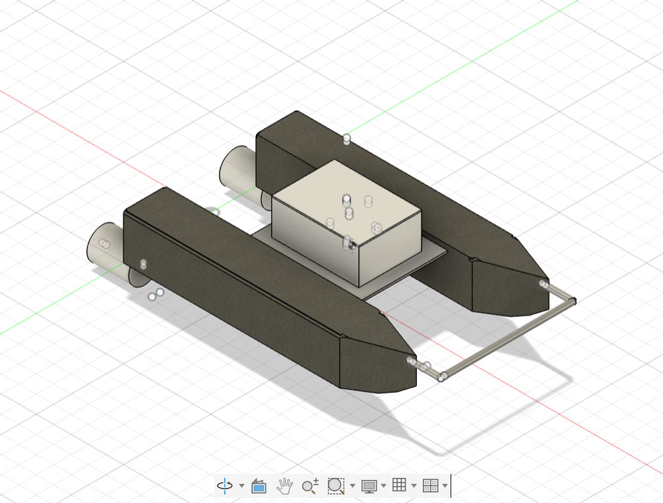
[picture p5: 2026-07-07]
hardware/mechanical/boat_3d.png

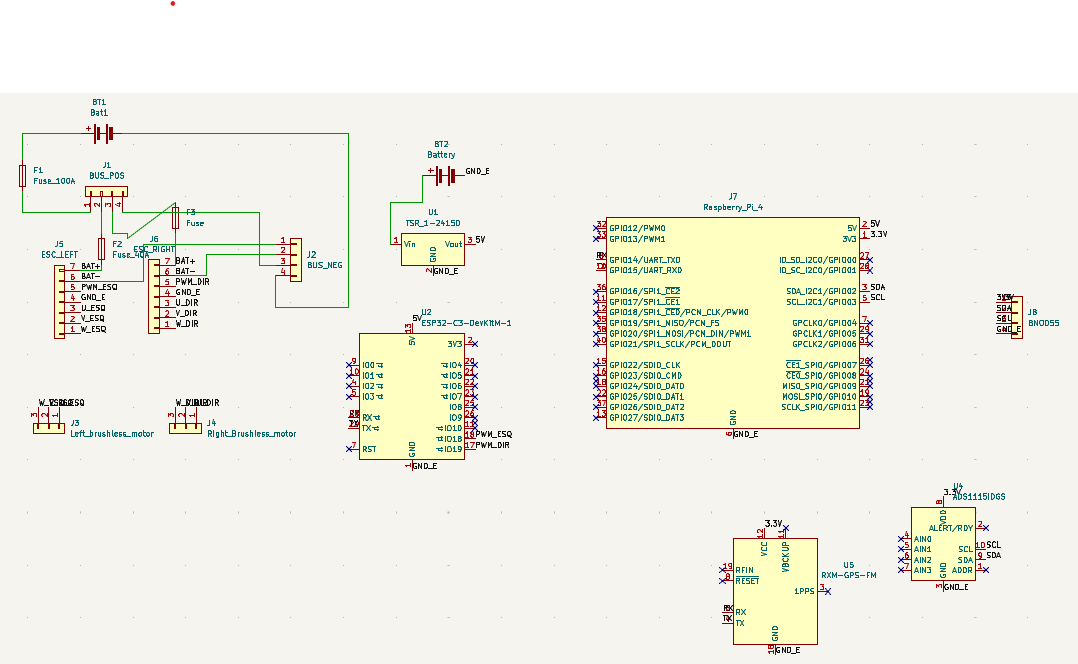
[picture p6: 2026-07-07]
hardware/electrical/schematic_v1.png

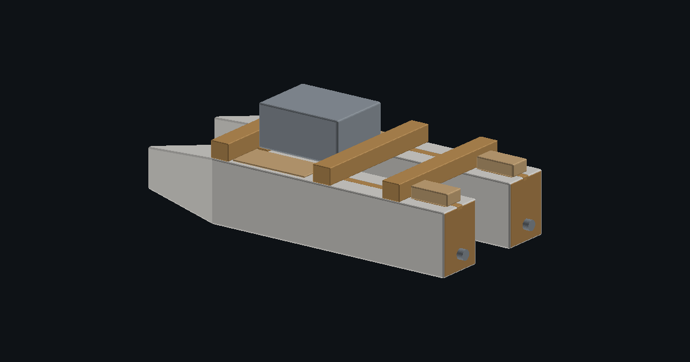
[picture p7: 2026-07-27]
website/assets/img/og.png

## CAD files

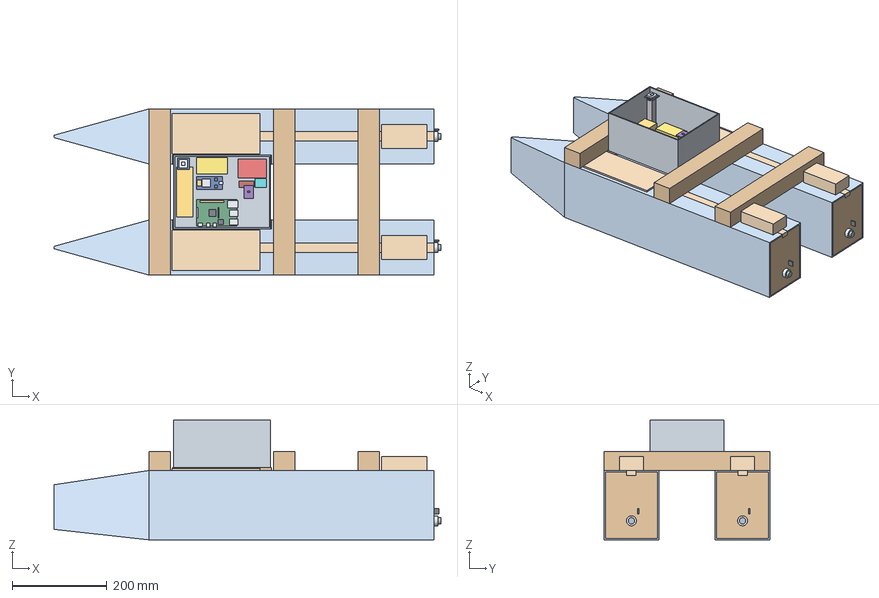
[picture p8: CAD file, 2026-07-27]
hardware/mechanical/SAILSAFE_concept_v6_4.step
815.0 x 350.0 x 252.0 mm
casco_direito
casco_esquerdo
travessa_T1
travessa_T2
travessa_T3
longarina_proa_dir
longarina_re_dir
escotilha_dir
bateria_5000_dir
transom_insert_dir
cobertura_ESC_dir
waterjet_dir
longarina_proa_esq
longarina_re_esq
escotilha_esq
bateria_5000_esq
transom_insert_esq
cobertura_ESC_esq
waterjet_esq
caixa_IP66
bateria_pi_2200
calco_IP66_1
calco_IP66_2
calco_IP66_3
calco_IP66_4
rpi4_pcb
rpi4_gpio
rpi4_gpio_pinos
rpi4_soc
rpi4_ram
rpi4_usb3
rpi4_usb2
rpi4_ethernet
rpi4_usbc
rpi4_hdmi0
rpi4_hdmi1
rpi4_csi
rpi4_dsi
esp32_pcb
esp32_wroom
esp32_antena
esp32_header_a
esp32_header_b
esp32_usb
esp32_btn_a
esp32_btn_b
suporte_BNO055
bno055_pcb
bno055_chip
bno055_header
suporte_GPS
gps_pcb
gps_antena
gps_lna
gps_header
conversor_DCDC_5V
distribuidor_fusiveis
sensor_corrente
ads1015
esc_dir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

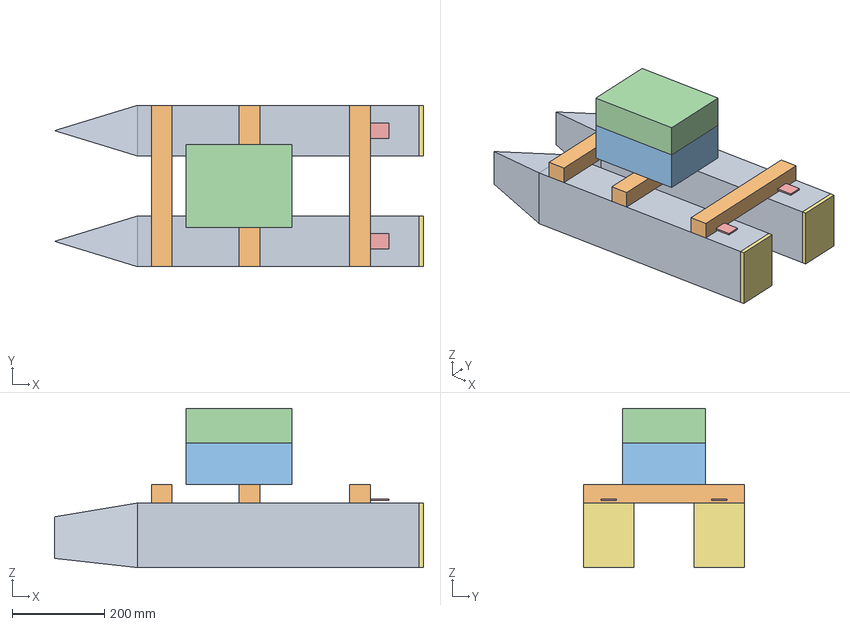
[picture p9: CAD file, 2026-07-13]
hardware/mechanical/SAILSAFE_concept_v2_advbrep.step
800.0 x 350.0 x 345.0 mm

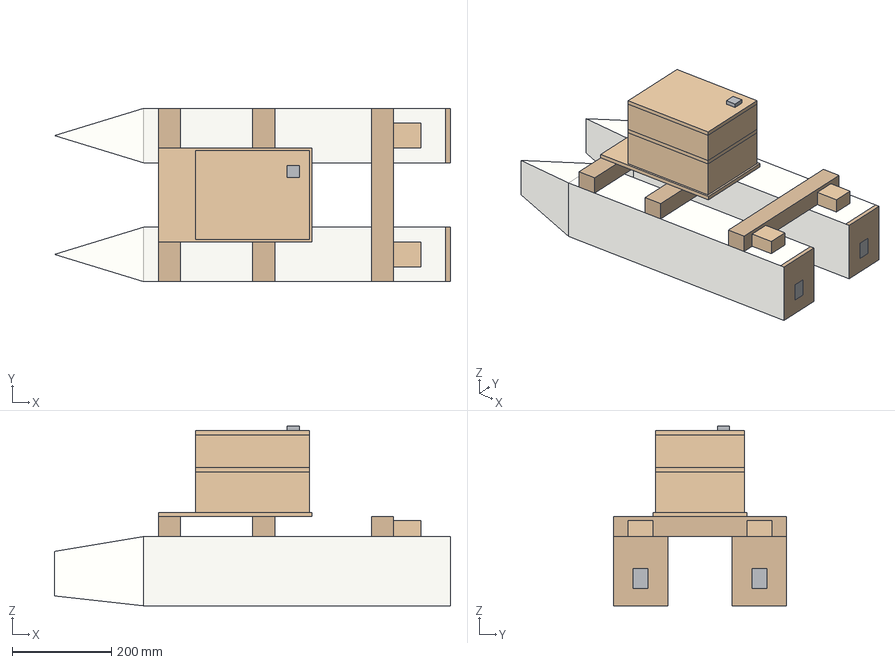
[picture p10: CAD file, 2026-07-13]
hardware/mechanical/SAILSAFE_concept_v3_wood.step
800.0 x 350.0 x 363.0 mm
PORT_HULL_XPS
STARBOARD_HULL_XPS
CROSSBEAM_1
CROSSBEAM_2
CROSSBEAM_3
PORT_ESC
STARBOARD_ESC
PORT_WATERJET
STARBOARD_WATERJET
PORT_TRANSOM_INSERT
STARBOARD_TRANSOM_INSERT
BOX_BASE_PLATE
BATTERY_BOX_BODY
BATTERY_BOX_LID
ELECTRONICS_BOX_BODY
ELECTRONICS_BOX_LID
LIPO_3S_5000MAH_PROPULSAO
LIPO_3S_2200MAH_ELETRONICA
BUSBAR_POSITIVO
BUSBAR_NEGATIVO
PORTA_FUSIVEL_PRINCIPAL
RASPBERRY_PI_4
ESP32_DEVKIT
DCDC_5V
IMU_BNO055
ADC_ADS1015
GPS_NEO8M_MODULO
GPS_ANTENA_ATIVA
PORT_ESC_COVER
STARBOARD_ESC_COVER

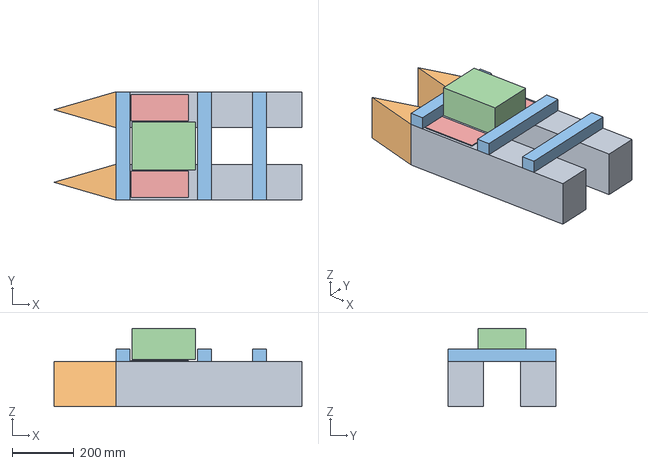
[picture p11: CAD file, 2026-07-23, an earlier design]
hardware/mechanical/archive/SAILSAFE_concept_v6_1.step
800.0 x 350.0 x 252.0 mm

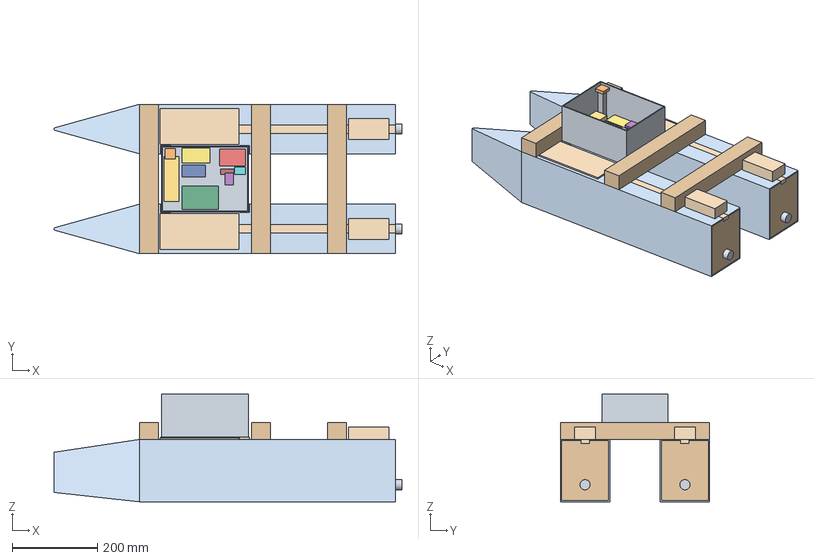
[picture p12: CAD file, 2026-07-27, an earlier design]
hardware/mechanical/SAILSAFE_concept_v6_3.step
815.0 x 350.0 x 252.0 mm
casco_direito
casco_esquerdo
travessa_T1
travessa_T2
travessa_T3
longarina_proa_dir
longarina_re_dir
escotilha_dir
bateria_5000_dir
transom_insert_dir
cobertura_ESC_dir
waterjet_dir
longarina_proa_esq
longarina_re_esq
escotilha_esq
bateria_5000_esq
transom_insert_esq
cobertura_ESC_esq
waterjet_esq
caixa_IP66
bateria_pi_2200
calco_IP66_1
calco_IP66_2
calco_IP66_3
calco_IP66_4
raspberry_pi_4
esp32_devkit
suporte_BNO055
bno055_imu
suporte_GPS
gps_modulo
conversor_DCDC_5V
distribuidor_fusiveis
sensor_corrente
ads1015
esc_dir
motor_dir
veio_motor_dir
esc_esq
motor_esq
veio_motor_esq

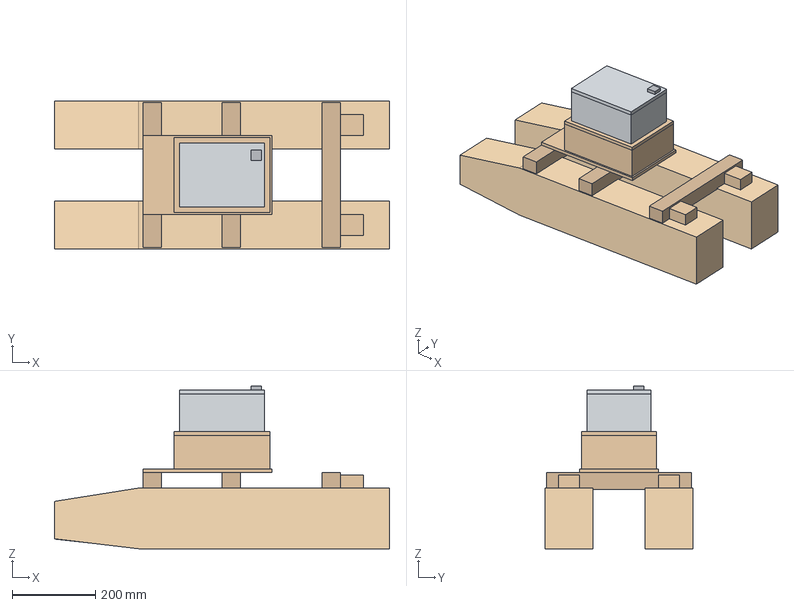
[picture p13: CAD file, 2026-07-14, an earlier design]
hardware/mechanical/archive/SAILSAFE_concept_v4.step
806.0 x 356.0 x 391.0 mm
PORT_HULL_XPS
STARBOARD_HULL_XPS
CROSSBEAM_1
CROSSBEAM_2
CROSSBEAM_3
PORT_ESC
STARBOARD_ESC
PORT_WATERJET
STARBOARD_WATERJET
PORT_TRANSOM_INSERT
STARBOARD_TRANSOM_INSERT
PORT_HULL_SKIN_PLY3
STARBOARD_HULL_SKIN_PLY3
PORT_DECK_STRINGER_20x10
STARBOARD_DECK_STRINGER_20x10
BOX_BASE_PLATE
BATTERY_BOX_BODY
BATTERY_BOX_LID
LIPO_3S_5000MAH_PROPULSAO
LIPO_3S_2200MAH_ELETRONICA
BUSBAR_POSITIVO
BUSBAR_NEGATIVO
PORTA_FUSIVEL_PRINCIPAL
IP66_BOX_BODY_204x155
IP66_BOX_LID
RASPBERRY_PI_4
ESP32_DEVKIT
DCDC_5V
IMU_BNO055
ADC_ADS1015
GPS_NEO8M_MODULO
GPS_ANTENA_ATIVA
PORT_ESC_COVER
STARBOARD_ESC_COVER

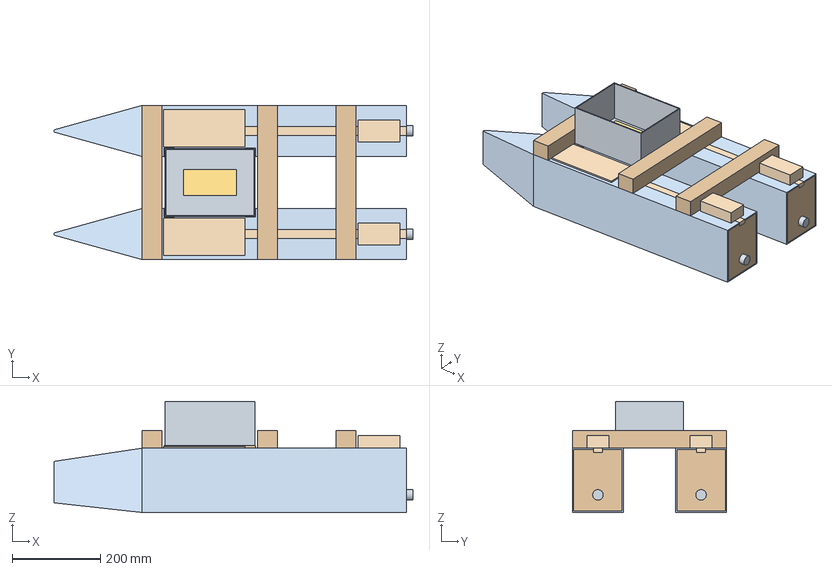
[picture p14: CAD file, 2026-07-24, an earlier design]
hardware/mechanical/SAILSAFE_concept_v6_2.step
815.0 x 350.0 x 252.0 mm
casco_direito
casco_esquerdo
travessa_T1
travessa_T2
travessa_T3
longarina_proa_dir
longarina_re_dir
escotilha_dir
bateria_5000_dir
transom_insert_dir
cobertura_ESC_dir
waterjet_dir
longarina_proa_esq
longarina_re_esq
escotilha_esq
bateria_5000_esq
transom_insert_esq
cobertura_ESC_esq
waterjet_esq
caixa_IP66
bateria_pi_2200
calco_IP66_1
calco_IP66_2
calco_IP66_3
calco_IP66_4

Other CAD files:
hardware/mechanical/SAILSAFE_concept_v2_coloured_cut.step
hardware/mechanical/SAILSAFE_concept_v2_fixed.step
hardware/mechanical/archive/SAILSAFE_concept_v2_wood.step
hardware/mechanical/archive/SAILSAFE_concept_v2.step
hardware/mechanical/archive/SAILSAFE_concept_v2_fixed.step
hardware/mechanical/SAILSAFE_concept_v2.step
hardware/mechanical/archive/SAILSAFE_concept_v1.step
hardware/mechanical/SAILSAFE_concept_v1.step
hardware/mechanical/SAILSAFE_concept_v2_wood.step
hardware/mechanical/SAILSAFE_concept_v6_3.stl
hardware/mechanical/archive/SAILSAFE_concept_v2_coloured_cut.step

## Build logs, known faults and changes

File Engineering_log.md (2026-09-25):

# Engineering log

A viabilidade do projeto SAILSAFE tem vindo a ser analisada desde fevereiro de 2026. Durante o período letivo, o foco esteve na exploração de opções de arquitetura, integração de subsistemas e definição dos principais requisitos técnicos.

Uma das tentativas iniciais incluiu o desenho de uma PCB para integração elétrica. Essa abordagem revelou-se inadequada para distribuição de potência, sobretudo pela ausência de planos de cobre e pela fase ainda inicial de experiência em desenho de PCBs. Ainda assim, essa tentativa foi útil para clarificar restrições do sistema e reforçar a decisão de adotar uma arquitetura elétrica mais conservadora e robusta.

Após várias iterações, foi definida uma arquitetura inicial suficientemente sólida para avançar para a fase de execução e validação experimental.

### 2026-07-05

#### Trabalho realizado

* Preparação inicial do código do ESP32 antes da chegada dos ESCs e do Raspberry Pi.
* Criação do esquema elétrico v1.

#### Problemas / limitações

* Curva de aprendizagem inicial do KiCad, com algum tempo necessário para compreender a ferramenta e estruturar corretamente o esquema.

#### Resultado do dia

* Base inicial de firmware preparada.
* Primeira versão do esquema elétrico concluída.

#### Próximo passo

* Refinar a arquitetura elétrica e continuar a consolidação da documentação principal.

### 2026-07-06

#### Trabalho realizado

* Firmware inicial do ESP32 preparado.
* Esquema elétrico v1 fechado.
* Documentação principal do projeto atualizada.
* BOM consolidada.
* Estratégia de controlo inicial por Wi-Fi definida.
* Recebido o Raspberry Pi 4 para o projeto.
* Configurado cartão microSD de 32 GB com Raspberry Pi OS.
* Configurado acesso remoto por SSH.
* Atualizado o sistema operativo do Raspberry Pi.
* Ativadas as interfaces I2C e Serial.
* Instaladas ferramentas base de desenvolvimento: Python 3, pip, venv, git, i2c-tools, screen e minicom.
* Criada a estrutura inicial de pastas do projeto no Raspberry Pi.

#### Decisões técnicas

* O kill-switch físico/remoto foi identificado como requisito futuro, mas adiado por motivos de orçamento.
* Foi decidido não ligar ainda ESCs, motores ou baterias de potência antes da validação da comunicação Raspberry Pi → ESP32.

#### Problemas / limitações

* O KiCad não incluía vários módulos específicos necessários para o projeto, obrigando ao uso de conectores genéricos no esquema.
* O esquema elétrico ainda requer melhorias de representação, embora os pontos principais de arquitetura estejam definidos.
* A preparação inicial do Raspberry Pi exigiu adaptação de hardware disponível para configurar o microSD.

#### Resultado do dia

* O projeto ficou num estado técnico muito mais sólido em termos de arquitetura, documentação e preparação para testes de bancada.
* O Raspberry Pi ficou operacional e preparado para integração futura com sensores e comunicação com o ESP32.
* O projeto encontra-se a aguardar a chegada dos componentes para iniciar testes físicos.

#### Próximo passo

* Testar comunicação Raspberry Pi → ESP32 por USB.

### 2026-07-07

#### Trabalho realizado

* Iniciada a criação do repositório GitHub do projeto SAILSAFE.
* Definida a estrutura inicial para documentação pública do projeto.
* Preparado o conteúdo inicial do README e da organização de ficheiros.
* Estruturados assistentes de IA para apoio à documentação, organização de tarefas e maior consistência na escrita técnica.

#### Decisões técnicas

* Foi decidido começar com uma estrutura simples de repositório, suficientemente organizada para ser mantida sem fricção excessiva.
* A documentação pública será construída de forma incremental, em vez de tentar formalizar tudo de uma só vez.

#### Problemas / limitações

* Curva de aprendizagem inicial do GitHub e da lógica de repositórios.
* Ainda sem integração total dos ficheiros técnicos no repositório.

#### Resultado do dia

* O projeto passou a ter uma base inicial para documentação pública e portefólio técnico.
* Ficou definido um caminho mais claro para organizar arquitetura, software, hardware e registos de evolução.
* Os assistentes de IA passaram a integrar o processo como ferramenta de apoio à produtividade e revisão técnica, sem substituir validação própria.

#### Próximo passo

* Fazer upload da documentação principal, esquema elétrico, ficheiro 3D e código do ESP32 para o repositório.

### 2026-07-08

#### Trabalho realizado

* Validada comunicação Raspberry Pi 4 → ESP32 por USB (ligação detetada como /dev/ttyUSB0).
* Confirmada interface USB-série CH341 no sistema.
* Validada comunicação UART entre Raspberry Pi e ESP32.
* Confirmado formato de comando textual:
L:10 R:10
* Validada conversão interna no ESP32:
percentagem → PWM (ex.: 10% → 1100 µs).
* Confirmado funcionamento de failsafe por perda de input (timeout → motores parados).
* Criado script Python no Raspberry Pi para envio periódico de comandos (keep-alive).
* Reestruturado parser UART do ESP32 para abordagem não bloqueante baseada em buffer + newline.

#### Problemas / limitações

* Cabo USB inicial não suportava dados (sem deteção do ESP32).
* Uso de screen causava envio inválido de comandos (carácter a carácter).
* Diferença entre documentação e implementação (PWM vs percentagem).
* Parser inicial (readStringUntil) introduzia risco de bloqueio.
* Conflito de acesso à porta série ao usar simultaneamente screen e Python.

#### Decisões técnicas

* Manter arquitetura:

  * Raspberry Pi → controlo de alto nível
  * ESP32 → controlo em tempo real + failsafe
* Congelar protocolo atual:
comando textual em percentagem (L:x R:y + newline)
* Limitar output inicial a 0–30% para segurança em bancada.
* Usar keep-alive como mecanismo normal e failsafe como redundância.

#### Resultado do dia

* Cadeia de controlo RPi → ESP32 validada em bancada.
* Protocolo básico de comando e segurança funcional.
* Base sólida estabelecida para integração futura com ESCs e motores.

#### Próximo passo

* Validar repetibilidade do keep-alive e comando STOP.
* Evoluir comando para modelo throttle + steering.
* Só depois iniciar integração com ESCs, motores e testes de potência.

### 2026-07-10

#### Trabalho realizado

* Aquisição de material elétrico para preparação da montagem física do sistema.
* Compra de cabos elétricos com secções de 6 mm², 1,5 mm² e 0,75 mm².
* Compra de conectores Wago para ligações de baixa corrente e sinais.
* Compra do carregador para as baterias LiPo.
* Aquisição de consumíveis e acessórios necessários à futura montagem elétrica.

#### Decisões técnicas

* Reservar o cabo de 6 mm² para o circuito de potência: bateria de 5000 mAh, fusíveis, barramentos e alimentação dos ESCs.
* Reservar o cabo de 1,5 mm² para alimentação da eletrónica, entrada do conversor DC-DC e ligação de referência entre os negativos dos dois subsistemas.
* Reservar o cabo de 0,75 mm², ou os fios originais dos módulos, para sinais PWM, GND de sinal e sensores.
* Manter os Wagos limitados a ligações de baixa corrente e sinais, não os utilizando no caminho principal de corrente dos motores.

#### Resultado do dia

* Material elétrico principal obtido para iniciar a preparação e os testes de montagem.
* Cablagem disponível com secções diferenciadas para potência, eletrónica e sinais.

#### Próximo passo

* Definir a arquitetura mecânica dos cascos, a localização das caixas, dos ESCs e das passagens de cabos antes de cortar ou montar a estrutura definitiva.

### 2026-07-11

#### Trabalho realizado

* Revisão crítica da arquitetura mecânica e elétrica do primeiro protótipo.
* Definição preliminar de dois cascos em XPS de célula fechada, revestidos com fibra de vidro e resina epóxi.
* Definição de reforços locais em contraplacado nas popas, pontos de fixação das travessas, base da caixa central e ponto de recuperação por corda.
* Definição preliminar de dimensões: aproximadamente 800 mm de comprimento total, 350 mm de largura total, cascos com cerca de 100–110 mm de largura e 130–140 mm de altura.
* Definição de três travessas estruturais: frontal, central e traseira.
* Análise da passagem dos cabos por conduítes no interior das travessas e, depois, pela face superior/interior dos cascos, devidamente fixos e protegidos.
* Revisão da localização dos ESCs, passando a privilegiar a instalação de cada ESC próximo do respetivo waterjet para reduzir o comprimento dos três cabos de fase do motor.
* Consolidação da separação das duas baterias: LiPo 5000 mAh dedicada à propulsão e LiPo 2200 mAh dedicada à eletrónica através do conversor DC-DC.
* Clarificação da estratégia de GND comum entre potência e eletrónica.

#### Decisões técnicas

* Não ligar os positivos das duas baterias e não colocar as baterias em paralelo.
* Ligar o negativo da bateria de potência ao barramento negativo de potência e o negativo da bateria de eletrónica ao ponto de GND da eletrónica.
* Criar uma única ligação de referência, em estrela, entre o GND da eletrónica e o barramento negativo de potência.
* Manter os fios GND que acompanham os sinais PWM dos dois ESCs, sem depender exclusivamente destes fios finos para estabelecer o GND comum do sistema.
* Usar cabo de 6 mm² entre a distribuição de potência e cada ESC.
* Usar cabo de 1,5 mm² para a ligação única de referência entre o GND eletrónico e o barramento negativo de potência.
* Isolar os fios de 5 V/BEC dos ESCs, caso existam, enquanto a eletrónica for alimentada pelo conversor DC-DC dedicado.
* Não fixar os waterjets diretamente ao XPS; utilizar contraplacado reforçado na popa, laminado e selado, com parafusos, anilhas e vedação adequados.
* Manter os ESCs acessíveis, protegidos contra água e com possibilidade de dissipação térmica; não os encapsular permanentemente em foam ou epóxi.

#### Riscos e limitações identificados

* A estimativa inicial de massa de 1,8–2,2 kg pode ser otimista para o protótipo completo; a massa real deve ser medida durante a construção.
* O XPS sem laminação não possui resistência suficiente para impactos, parafusos ou cargas concentradas.
* Cabos exteriores mal fixos podem entrar na admissão dos waterjets, sofrer abrasão ou conduzir água para as caixas.
* A inexistência de kill-switch físico/remoto mantém a restrição de testes na água com corda de recuperação, potência limitada e supervisão direta.

#### Resultado do dia

* Conceito mecânico preliminar consolidado para uma construção híbrida: XPS + fibra de vidro + epóxi, com reforços estruturais em contraplacado.
* Percurso preliminar de cabos e localização dos ESCs definidos.
* Arquitetura de duas baterias e GND comum clarificada sem união dos positivos.
* Base técnica preparada para atualizar o documento de arquitetura para a versão v1.5.

#### Próximo passo

* Confirmar as dimensões físicas e a massa de todos os componentes.
* Fazer uma disposição à escala real em cartão antes de cortar XPS ou madeira.
* Confirmar o modelo exato, o procedimento de arming e a presença de BEC nos ESCs.
* Comprar os materiais mecânicos e de laminação após confirmar disponibilidade, compatibilidade e quantidades.

### 2026-07-12
 
#### Trabalho realizado
 
* Compra de contraplacado para os cascos e para a estrutura.
* Iteração de vários modelos CAD (.step); consolidada a versão v3 do modelo: caixas centrais ocas em contraplacado de 9 mm com tampas, placa base a distribuir a carga da pilha de caixas pelas travessas 1 e 2, componentes internos modelados (baterias, bus bars, fusível principal, Raspberry Pi 4, ESP32, DC-DC, BNO055, ADS1015, módulo GPS), antena GPS relocalizada para o topo da tampa e coberturas de proteção sobre os ESCs.
* Revisão do orçamento de massa com base nos volumes reais do modelo v3: ≈4,5–5,5 kg tal como modelado (madeira ≈2,6 kg, XPS ≈0,74 kg, fibra+epóxi ≈0,45 kg, restantes componentes ≈1,3 kg), invalidando a estimativa anterior de 1,8–2,2 kg.
* Análise de compatibilidade massa/potência: a 5,5 kg, ≈110 W/kg e impulso/peso estimado de 0,4–0,55 — adequado a navegação em deslocamento e ao OBJ-001; planeio excluído. Calado estimado ≈31 mm (≈6 mm/kg), favorável à submersão das admissões dos waterjets.
* Documento de arquitetura atualizado para v1.6: REQ-MEC-003, secções 5.3 e 17.2 e histórico de revisões.
* Conversor DC-DC colocado em funcionamento, com saída estimada em ≈5,1 V reais.
* Diagnóstico do multímetro: erro de escala consistente de ×1,86 confirmado com três referências independentes (LiPo a 11,8 V confirmados pelo carregador vs 22 lidos; pilha alcalina ~1,6 V vs 3,00 lidos; leitura do DC-DC coerente com o mesmo fator).
#### Decisões técnicas
 
* Alvo de saída do DC-DC fixado em 5,1 V (compensação da queda na cablagem até ao Raspberry Pi); ligação do Pi condicionada a verificação sob carga.
* Validação do DC-DC feita por medição comparativa contra referência conhecida, dado o erro de escala do multímetro; valores absolutos deste multímetro considerados não fiáveis até substituição.
* Meta de aligeiramento estrutural registada na v1.6: contraplacado de 5–6 mm nas caixas, travessas furadas ou em tubo de alumínio 20×20 e possível unificação das duas caixas (objetivo 3,5–4,0 kg).
#### Problemas / limitações
 
* Multímetro com leituras infladas por fator ≈1,86 (referência interna degradada); compartimento da pilha inacessível até agora, substituição pendente.
* As leituras erradas causaram falso alarme inicial (baterias aparentemente a 21–22 V e DC-DC aparentemente a 9,4–9,6 V), consumindo tempo de diagnóstico.
* A compra de contraplacado para os cascos pode implicar mudança da arquitetura de cascos (XPS + fibra → contraplacado), com impacto direto no orçamento de massa da v1.6; decisão ainda não formalizada.
#### Resultado do dia
 
* DC-DC operacional com saída estimada correta; baterias validadas como saudáveis (11,8 V confirmados pelo carregador).
* Modelo CAD v3 com componentes integrados e correções estruturais; documentação de arquitetura atualizada para v1.6 com orçamento de massa realista.
* Material estrutural (contraplacado) adquirido.
#### Próximo passo
 
* Adquirir multímetro fiável antes de qualquer teste com ESCs e motores.
* Verificar a saída do DC-DC sob carga e remedir a referência no fim da sessão.
* Decidir formalmente a arquitetura dos cascos (XPS + fibra vs contraplacado) e refazer o cálculo de massa antes de qualquer corte definitivo.
* Manter a disposição à escala real antes do corte, conforme definido a 2026-07-11.

### 2026-07-13
 
#### Trabalho realizado
 
* Consolidação física da cadeia de alimentação de 5 V: soldaduras reforçadas, fusível adicionado ao circuito e termorretráctil aplicado em todas as ligações.
* Validação da saída do conversor DC-DC: 5 V estáveis confirmados após a consolidação.
* Análise comparativa das duas vias de alimentação do Raspberry Pi 4: entrada USB-C (com cabo A-para-C descarnado) vs pinos GPIO (5 V nos pinos 2/4, GND nos pinos 6/14).
* Avaliação dos cabos disponíveis: cabo A-para-C descarnado considerado subdimensionado para a corrente do Pi 4 (condutores finos, retorno pela malha de blindagem); identificado cabo micro-B para a ligação Pi → ESP32.
* Definição do procedimento de identificação dos pinos GPIO com multímetro (continuidade pino 2 ↔ pino 4; continuidade pino 6 ↔ carcaça USB) e do procedimento de soldadura (solda no topo do pino, ≤3–4 s, termorretráctil, alívio de tensão com abraçadeira ao furo de montagem).
#### Decisões técnicas
 
* Alimentar o Raspberry Pi 4 pelos pinos GPIO (2/4 = +5 V; 6/14 = GND) com fio de 0,75 mm², usando os dois pares para dividir corrente e dar redundância mecânica; via USB-C mantida como alternativa.
* Alimentar o ESP32 exclusivamente pelo cabo USB a partir do Pi (dados + alimentação); não ligar VIN em simultâneo com USB.
* Instalar condensador eletrolítico (470–1000 µF, ≥10 V) junto ao ponto de entrega no Pi, como reservatório para picos de corrente; cerâmico de 100 nF a adicionar quando disponível.
* Riscos de soldadura identificados: ponte entre pino 2 (5 V) e pino 1 (3,3 V) é destrutiva; verificação final de continuidade 5 V↔GND e 5 V↔3,3 V obrigatória antes de dar corrente.
* Critério de aceitação da alimentação: vcgencmd get_throttled = 0x0 com o sistema em bateria.
#### Problemas / limitações
 
* Apenas disponível o condensador eletrolítico; o cerâmico de 100 nF fica pendente (impacto reduzido: filtra ruído de alta frequência, não afeta a estabilidade de tensão média).
* Multímetro de confiança ainda por adquirir; medições de corrente e verificações finais dependem dele.
#### Resultado do dia
 
* Cadeia de alimentação de 5 V consolidada e protegida (fusível + termorretráctil), com saída estável.
* Arquitetura de alimentação do par Pi/ESP32 decidida e documentada: DC-DC → GPIO do Pi; Pi → USB → ESP32.
* Procedimentos de identificação de pinos, soldadura e verificação definidos antes da execução.
#### Próximo passo
 
* Soldar os rabichos de 0,75 mm² aos pinos GPIO com o procedimento definido.
* Primeiro arranque do Pi em bateria; verificar get_throttled; só depois ligar o ESP32 e repetir.
* Testar o cabo micro-B (deteção de /dev/ttyUSB0) e correr keep-alive + failsafe integralmente em bateria.
* Comprar multímetro e condensador cerâmico de 100 nF.

### 2026-07-14

#### Trabalho realizado
- Soldadura do condensador eletrolítico junto ao ponto de alimentação do Raspberry Pi 4.
- Soldadura dos cabos de alimentação diretamente aos pinos de alimentação do Raspberry Pi:
  - +5 V nos pinos físicos 2 e 4;
  - GND nos pinos físicos 6 e 14.
- Isolamento das ligações e preparação da cablagem para alimentar o Raspberry Pi através do conversor DC-DC.
- Primeiro ensaio de alimentação do Raspberry Pi através do circuito do barco.
- Observação dos LEDs de alimentação e atividade durante o arranque.
- Teste comparativo com alimentação através da entrada USB-C.
- Ligação do cartão microSD ao computador para diagnóstico.
- Confirmação de que o cartão era reconhecido fisicamente e de que a partição `bootfs` permanecia acessível.
- Regravação do Raspberry Pi OS através do Raspberry Pi Imager.
- Nova configuração do Wi-Fi, hostname, utilizador e acesso por SSH.

#### Decisões técnicas
- Não alimentar simultaneamente o Raspberry Pi pela entrada USB-C e pelos pinos GPIO.
- Validar inicialmente o Raspberry Pi sem o ESP32, sensores ou outros periféricos ligados.
- Confirmar primeiro o funcionamento do Raspberry Pi através de uma fonte USB-C de confiança.
- Repetir posteriormente o teste com alimentação exclusiva através da bateria e do conversor DC-DC.
- Utilizar `sudo poweroff` antes de interromper fisicamente a alimentação, sempre que existir acesso ao sistema.
- Manter `vcgencmd get_throttled` como principal verificação interna da qualidade da alimentação.
- Adotar `throttled=0x0` como critério inicial de aceitação da alimentação pelo circuito do barco.

#### Problemas / limitações
- Durante o primeiro ensaio existiu receio de danificar o Raspberry Pi devido à alimentação direta pelos pinos GPIO.
- A alimentação foi interrompida antes de o sistema concluir o arranque e sem encerramento controlado.
- Após a interrupção, ocorreu provável corrupção de ficheiros ou da configuração do Raspberry Pi OS no cartão microSD.
- O Raspberry Pi deixou de ficar acessível por SSH e não apareceu de forma fiável na rede local.
- Alguns endereços IP encontrados respondiam a `ping`, mas recusavam ligações na porta 22, dificultando a identificação do Raspberry Pi.
- A tentativa de ativar manualmente o SSH através da partição `bootfs` não resolveu imediatamente o problema.
- Foi necessário regravar o cartão microSD para recuperar uma instalação limpa e eliminar a incerteza causada pela possível corrupção de ficheiros.

#### Resultado do dia
- Não foram observados sinais imediatos de dano elétrico no Raspberry Pi, como fumo, cheiro a queimado, aquecimento rápido ou perda do LED vermelho de alimentação.
- O cartão microSD não ficou fisicamente danificado: continuou a ser reconhecido pelo computador e a partição `bootfs` permaneceu acessível.
- A falha de acesso foi associada a corrupção lógica ou perda da configuração do sistema, e não a uma avaria física confirmada.
- O Raspberry Pi OS foi regravado com sucesso.
- O hostname `sailsafe-pi`, o utilizador, o Wi-Fi e o acesso por SSH foram novamente configurados.
- O Raspberry Pi voltou a ficar preparado para acesso remoto.
- A alimentação através do circuito soldado ficou pendente de validação completa com o Raspberry Pi arrancado exclusivamente pela bateria e pelo conversor DC-DC.

#### Lições aprendidas
- O LED vermelho confirma a presença de alimentação, mas não garante, por si só, que a tensão esteja correta e estável.
- O LED verde pode piscar intensamente durante o arranque e apenas ocasionalmente depois, sem que isso represente necessariamente uma falha.
- Interromper a alimentação durante a atividade do cartão pode corromper o sistema de ficheiros sem danificar fisicamente o microSD.
- O cartão microSD deve ser regravado quando a instalação ainda não contém dados importantes e o estado do sistema fica incerto.
- A alimentação do Raspberry Pi deve ser validada de forma incremental, começando pelo Raspberry Pi isolado.
- Deve existir um procedimento de encerramento seguro antes de desligar fisicamente a alimentação.
- A validação visual dos LEDs deve ser complementada por verificações internas do sistema.

#### Próximo passo
- Confirmar o arranque e o acesso por SSH com alimentação USB-C.
- Encerrar corretamente o Raspberry Pi com `sudo poweroff`.
- Retirar completamente a alimentação USB-C.
- Arrancar o Raspberry Pi exclusivamente através da bateria e do conversor DC-DC.
- Confirmar que não existe nenhuma outra fonte ligada simultaneamente à linha de 5 V.
- Após o arranque, executar `vcgencmd get_throttled`.
- Confirmar que o resultado é `throttled=0x0`.
- Executar `uptime` para verificar se o Raspberry Pi não reiniciou.
- Consultar os registos de possíveis problemas de alimentação com `dmesg | grep -i -E "under-voltage|voltage|thrott"`.
- Manter o Raspberry Pi ligado durante 10–15 minutos e repetir as verificações.
- Só depois ligar o ESP32 por USB e repetir o teste de estabilidade da alimentação.

### 2026-07-15

#### Trabalho realizado
- Validação completa da alimentação do Raspberry Pi 4 através do conversor DC-DC ligado aos pinos GPIO.
- Execução de stress test (CPU 100%) para validação de estabilidade elétrica.
- Monitorização do estado de alimentação através de vcgencmd get_throttled.
- Confirmação de ausência de undervoltage e throttling durante operação sob carga.
- Configuração e validação do systemd para execução automática do software.
- Criação do serviço sailsafe.service em /etc/systemd/system/.
- Debug de erros de configuração do systemd:
  - Correção de paths inválidos (/etc/system vs /etc/systemd/system).
  - Correção do utilizador (pi → goncalo).
  - Correção do caminho do script Python.
- Integração inicial com GitHub:
  - Clonagem do repositório SAILSAFE para o Raspberry Pi.
  - Introdução do fluxo de deploy baseado em git (git pull).
- Diagnóstico de falha de execução do serviço:
  - Identificação de ausência de código no Raspberry Pi.
  - Identificação de inconsistência na estrutura do repositório.
- Revisão e refactor do código Python de controlo:
  - Implementação de retry automático da porta serial.
  - Tratamento de exceções na escrita e leitura.
  - Reconexão automática em caso de falha.
  - Tornar o código compatível com execução via systemd.

#### Decisões técnicas
- Utilizar systemd como mecanismo de execução automática do software no Raspberry Pi.
- Utilizar GitHub como fonte única de verdade para o código (deploy via git pull).
- Definir um ponto de entrada único para o sistema: software/main.py.
- Implementar robustez mínima no código antes de integração com hardware (retry + reconexão).
- Adiar implementação de udev rules para fixação da porta serial para fase seguinte.
- Manter potência de saída limitada (≈10%) para testes iniciais.

#### Problemas / limitações
- Estrutura do repositório GitHub inconsistente e não alinhada com o systemd.
- Ausência inicial do código no Raspberry Pi após reset do sistema.
- Dependência de path fixo (/dev/ttyUSB0) sem garantia de persistência.
- Possível ausência de dependências Python (ex: pyserial).
- Ausência de kill-switch físico/remoto (restrição já conhecida).
- Código ainda sem validação completa com hardware real (ESP32).

#### Resultado do dia
- Alimentação do Raspberry Pi validada sob carga máxima (sem throttling).
- systemd configurado corretamente e funcional ao nível de sistema.
- Pipeline de deploy (GitHub → Raspberry Pi) definido e operacional.
- Código Python atualizado para versão robusta compatível com operação contínua.
- Sistema global próximo de execução autónoma.

#### Riscos identificados
- Porta serial dinâmica (/dev/ttyUSB0 pode mudar após reboot).
- Falha de comunicação com ESP32 pode levar a ausência de controlo.
- Ausência de kill-switch mantém risco operacional em testes reais.
- Estrutura do repositório pode causar erros de integração futuros.

#### Próximo passo
- Confirmar estrutura final do repositório:
  - SAILSAFE/software/main.py
- Executar teste manual do script Python no Raspberry Pi.
- Validar funcionamento do serviço systemd (estado active running).
- Instalar dependências Python necessárias (pyserial).
- Testar comunicação real Raspberry Pi ↔ ESP32.
- Implementar udev rule para fixar a porta serial.

### 2026-07-16

#### Trabalho realizado
- Revisão crítica do plano de desenvolvimento com base em restrições logísticas (impossibilidade de receber encomendas durante duas semanas).
- Definição de estratégia de desenvolvimento em duas fases:
  - Semana fora: foco exclusivo em software e integração lógica.
  - Regresso: início da construção da estrutura mecânica com apoio especializado.
- Análise detalhada do sistema de segurança e decisão de adiar a implementação do kill-switch remoto baseado em RC.
- Introdução de uma solução temporária de segurança:
  - utilização de loop key XT90 como método de corte manual de energia.
- Revisão da arquitetura elétrica para acomodar a ausência de kill-switch remoto:
  - bateria → loop key → fusível principal → distribuição → ESCs.
- Planeamento da distribuição de fusíveis:
  - fusível principal (~80A estimado)
  - fusíveis individuais de 40A por ESC.
- Definição de política de testes para fase atual:
  - testes de motores apenas em bancada
  - potência limitada
  - sistema fisicamente contido
- Decisão de adiar aquisição de sistema RC (rádio + receiver) para fase posterior, por restrições de orçamento.
- Consolidação da estratégia de compras:
  - prioridade a conectores (XT90, XT60), fusíveis e solução de corte manual
  - adiamento de componentes não críticos para a fase atual.
- Planeamento detalhado do uso do tempo durante as próximas semanas:
  - desenvolvimento de software durante o período fora
  - desenvolvimento mecânico após regresso

#### Decisões técnicas
- Implementar loop key XT90 como solução de kill manual temporária.
- Adiar sistema de kill-switch remoto baseado em RC para fase posterior.
- Adiar aquisição de rádio e receiver devido a restrições de orçamento e ausência de necessidade imediata.
- Separar claramente fases de desenvolvimento:
  - Fase 1: software e integração lógica
  - Fase 2: estrutura e integração física
- Limitar testes de potência até existência de sistema de segurança mais robusto.

#### Problemas / limitações
- Ausência de conectores adicionais XT90 limita montagem elétrica completa.
- Impossibilidade de receber encomendas durante duas semanas impede avanço em subsistema de potência.
- Ausência de multímetro impede validação elétrica detalhada (tensão, continuidade, quedas).
- Ausência de kill-switch remoto limita segurança em testes com motores.
- Dependência de ferramentas e apoio externo para construção da estrutura.

#### Resultado do dia
- Estratégia global do projeto ajustada à realidade logística e financeira.
- Arquitetura elétrica simplificada e adaptada à fase atual.
- Plano de desenvolvimento para as próximas semanas claramente definido.
- Riscos principais identificados e mitigados dentro do possível.

#### Riscos identificados
- Dependência de corte manual de energia (loop key) como único mecanismo de segurança.
- Potencial erro de ligação elétrica sem instrumentação adequada.
- Possível atraso na integração de potência devido a falta de componentes.
- Risco de comportamento inesperado dos ESCs em cortes sob carga.

#### Próximo passo
- Finalizar software do Raspberry Pi:
  - garantir execução estável via systemd
  - implementar logging básico
  - integrar leitura da IMU
- Validar comunicação contínua Raspberry Pi ↔ ESP32.
- Preparar estrutura do código para integração futura do controlo (heading hold).
- Definir layout físico preliminar da estrutura antes da construção.
- Adquirir conectores e componentes elétricos assim que possível após regresso.

### 2026-07-17

#### Trabalho realizado
- Revisão do feedback técnico recebido sobre as prioridades imediatas do projeto: implementação de um corte físico independente, desenvolvimento de heading hold antes da navegação por waypoints e logging completo desde o início dos testes.
- Revisão da arquitetura de segurança da Fase 1, tendo em conta a indisponibilidade temporária de um kill-switch remoto.
- Definição de uma solução temporária de corte manual através de uma loop key com conector XT90.
- Definição da cadeia elétrica de segurança: bateria de propulsão → loop key XT90 → fusível principal → distribuição → fusíveis individuais → ESCs.
- Atualização do documento principal de arquitetura da versão v1.9 para v1.10.
- Adição da secção 10.1 — Arquitetura de Segurança Temporária — Fase 1.
- Adição de SAFE-007 para falha total do sistema, com corte manual imediato de energia através da loop key.
- Adição de TEST-011 para validar o comportamento do sistema durante a remoção da loop key.
- Adição de RISK-009, relativo ao possível comportamento imprevisível dos ESCs durante um corte de energia sob carga.
- Atualização de OPEN-008 para registar a loop key como solução temporária e manter o kill-switch remoto como requisito obrigatório antes de operação autónoma ou testes sem corda.
- Inclusão explícita da loop key no diagrama da arquitetura elétrica.
- Revisão do estado do fusível principal de 100 A.
- Definição do plano de desenvolvimento do software até 2026-07-26.
- Separação entre as funcionalidades que podem ser desenvolvidas sem hardware físico e as validações que dependem da chegada da loop key, GPS, ESCs e restantes componentes.
- Definição de uma abordagem baseada em fontes simuladas para desenvolver e testar o heading hold e a navegação por waypoints sem depender imediatamente do BNO055 ou do GPS físico.

#### Decisões técnicas
- Utilizar temporariamente uma loop key XT90 como meio manual de corte da alimentação da propulsão durante a Fase 1.
- Instalar a loop key entre a bateria de propulsão e o fusível principal, garantindo que a sua remoção desenergiza todo o circuito de potência dos ESCs.
- Manter o kill-switch remoto independente como requisito obrigatório antes de testes sem corda, operação autónoma ou operação afastada da margem.
- Não considerar a loop key como substituto definitivo do kill-switch remoto, uma vez que exige a presença física do operador e não permite corte à distância.
- Não energizar os ESCs antes de existir um meio físico, imediato e independente de cortar a alimentação.
- Não transportar os ESCs para os trabalhos de software enquanto não estiver prevista a sua energização; os ESCs poderão ser levados apenas para inspeção, identificação de ligações ou preparação da montagem.
- Manter os testes em água proibidos enquanto não existir um sistema de recuperação por corda, supervisão direta e potência limitada.
- Alterar o estado do fusível principal de 100 A de “confirmado” para estimativa baseada no dimensionamento teórico de dois ESCs de 40 A.
- Validar o valor definitivo do fusível principal apenas depois de existirem medições reais de corrente, incluindo picos de arranque e funcionamento simultâneo dos dois motores.
- Implementar e validar primeiro o heading hold, antes de avançar para a navegação por waypoints.
- Começar o heading hold com um controlador proporcional simples, adiando a utilização de PI ou PID até existirem dados físicos que justifiquem maior complexidade.
- Normalizar o erro angular do heading para o intervalo entre −180° e +180°, evitando erros durante a transição entre 359° e 0°.
- Separar as fontes de dados da lógica de controlo, permitindo utilizar heading e posição simulados enquanto o BNO055 e o GPS físico não estiverem disponíveis.
- Criar uma fonte de posição simulada para desenvolver o cálculo de distância, bearing, raio de chegada e transição entre waypoints.
- Identificar explicitamente todos os dados simulados como sintéticos, evitando apresentá-los como medições reais.
- Implementar o logging antes dos testes físicos dos ESCs e antes da validação da navegação autónoma.
- Criar um ficheiro CSV diferente para cada sessão, contendo timestamps, estado do sistema, modo de controlo, comandos, estado da comunicação, failsafe, heading, GPS e dados dos waypoints.
- Implementar uma máquina de estados com, pelo menos, BOOT, DISARMED, ARMED, RUNNING, FAILSAFE e ERROR.
- Garantir que o sistema inicia sempre em estado seguro e que os comandos de movimento são rejeitados enquanto o sistema estiver desarmado.
- Garantir que o regresso da comunicação após um failsafe não provoca movimento automático; deverá ser exigido um novo comando explícito de arming.
- Manter o comando STOP com prioridade absoluta sobre qualquer modo manual ou automático.
- Definir como objetivo para 2026-07-26 a conclusão do software MVP em bancada lógica e simulação, sem declarar ainda o sistema autónomo como fisicamente validado.

#### Problemas / limitações
- A loop key XT90 ainda não se encontra disponível, ficando prevista apenas para a semana seguinte.
- A ausência da loop key impede, por razões de segurança, a energização dos ESCs através da bateria de propulsão.
- O GPS físico ainda não se encontra disponível.
- A integração e calibração física do BNO055 não estão concluídas.
- O valor de 100 A do fusível principal ainda não foi confirmado através de medições reais.
- O comportamento dos ESCs durante a inicialização, arming, timeout, corte de energia e reposição da alimentação permanece por validar.
- O neutro real, a gama de comando e a resposta dos ESCs ainda não foram medidos.
- A afinação do heading hold não pode ser concluída apenas por simulação, pois dependerá da resposta física do barco, da inércia, dos waterjets, do vento e das condições da água.
- A navegação por waypoints poderá ser implementada com dados simulados, mas continuará pendente de validação com GPS físico e testes na água.
- O prazo até 2026-07-26 permite concluir o MVP de software, mas não permite garantir a validação física completa de todos os subsistemas que ainda não estão disponíveis.

#### Resultado do dia
- Documento principal de arquitetura atualizado e fechado como SAILSAFE Architecture v1.10.
- Arquitetura temporária de segurança com loop key XT90 definida e documentada.
- Limitações da solução temporária e condições obrigatórias para testes registadas formalmente.
- Estado do fusível principal corrigido para refletir que o valor de 100 A continua por validar experimentalmente.
- Decisão tomada de não energizar os ESCs antes da chegada da loop key ou da disponibilidade de outro meio de corte físico devidamente dimensionado.
- Confirmado que a ausência temporária da loop key e do GPS não bloqueia o desenvolvimento do software.
- Definida uma estratégia de desenvolvimento com GPS e heading simulados.
- Heading hold priorizado antes da navegação por waypoints.
- Logging definido como funcionalidade obrigatória antes dos testes físicos.
- Plano de trabalho estabelecido para concluir o software MVP até 2026-07-26.
- Validações físicas pendentes claramente separadas das funcionalidades implementáveis em simulação.

#### Lições aprendidas
- Um failsafe por timeout protege contra perda de comunicação, mas não cobre todos os modos de falha possíveis do software, ESP32 ou ESCs.
- Um botão STOP por software não substitui um corte físico independente da eletrónica de controlo.
- Uma solução temporária de segurança deve ter as suas limitações explicitamente documentadas, não podendo ser apresentada como equivalente à solução definitiva.
- “Implementado” e “validado fisicamente” são estados diferentes e devem ser registados separadamente.
- A ausência temporária de sensores ou atuadores não impede o desenvolvimento quando o software utiliza interfaces bem separadas e fontes simuladas.
- O heading hold deve ser validado antes dos waypoints, porque a navegação por GPS depende de um controlo de rumo estável e previsível.
- O logging deve ser desenvolvido antes dos ensaios físicos, para garantir que qualquer falha ou comportamento inesperado pode ser posteriormente analisado.
- Os dados sintéticos são adequados para testar a lógica, desde que sejam claramente identificados e não sejam confundidos com medições reais.
- A complexidade do controlador deve aumentar apenas quando os resultados experimentais demonstrarem essa necessidade.

#### Próximo passo
- Consolidar e congelar o protocolo de comunicação Raspberry Pi → ESP32.
- Rever o parser não bloqueante do ESP32 e confirmar a utilização de newline como delimitador.
- Implementar uma máquina de estados explícita no ESP32.
- Garantir arranque em DISARMED e rejeição de movimento antes de um comando ARM válido.
- Confirmar o funcionamento do keep-alive a 5 Hz e do timeout de comunicação.
- Garantir que STOP tem prioridade sobre todos os restantes comandos.
- Criar o sistema de logging por sessão no Raspberry Pi.
- Criar fontes simuladas de heading e posição.
- Implementar e testar a normalização do erro angular.
- Implementar o controlador proporcional inicial de heading hold.
- Desenvolver a gestão de waypoints utilizando posições sintéticas.
- Adiar a energização dos ESCs até à chegada da loop key e à preparação da cadeia de potência protegida por fusíveis.

### 2026-07-18

#### Trabalho realizado
- Configuração completa de autenticação SSH no Raspberry Pi para integração com GitHub.
- Geração de chave SSH (ed25519) e validação de autenticação sem password.
- Alteração do remote do repositório de HTTPS para SSH (git@github.com).
- Validação da ligação através de git fetch.
- Diagnóstico da ausência de ficheiros de comunicação (serial_link.py) no sistema local.
- Identificação de inconsistências entre repositório GitHub e diretório local.
- Execução de git pull para sincronização completa com o repositório remoto.
- Análise da estrutura resultante após sincronização.
- Identificação de estrutura incorreta no repositório:
  - pasta com nome inválido ("rasberry pi")
  - duplicação de diretórios (rasberrypi vs software/rasberry pi)
- Tentativas de reorganização manual do sistema de ficheiros.
- Identificação de erros recorrentes devido a:
  - typos nos paths
  - uso incorreto de nomes com espaços
- Localização correta do ficheiro serial_link.py dentro de:
  software/rasberry pi/
- Início do processo de refactor da estrutura de pastas para arquitetura modular:
  - raspberrypi/comms
  - raspberrypi/control

#### Decisões técnicas
- Utilizar exclusivamente SSH para operações Git no Raspberry Pi.
- Utilizar GitHub como fonte de verdade única para o código.
- Corrigir a estrutura do repositório antes de avançar com desenvolvimento.
- Adotar uma arquitetura modular:
  - comms (comunicação)
  - control (lógica de decisão)
  - main (orquestração)
- Eliminar nomes inválidos (espaços e typos) em diretórios.
- Priorizar consistência de naming como requisito de arquitetura.
- Adiar desenvolvimento de lógica de controlo até estrutura do projeto estar estável.

#### Problemas / limitações
- Estrutura do repositório inconsistente (pastas duplicadas e mal nomeadas).
- Presença de espaços em nomes de diretórios (ex: "rasberry pi") a dificultar comandos shell.
- Múltiplos typos nos paths (rasberry, rasberypi, rasberrpi).
- Dificuldade em localizar ficheiros devido a inconsistência estrutural.
- Confusão entre diretório local e conteúdo sincronizado do Git.
- Falta de disciplina inicial no versionamento (ficheiros fora do repo).
- Curva de aprendizagem do sistema de ficheiros Linux e comandos CLI.

#### Resultado do dia
- Sistema Git totalmente funcional via SSH.
- Ligação Raspberry Pi ↔ GitHub estabilizada.
- Repositório sincronizado com sucesso.
- Ficheiro serial_link.py confirmado no repositório.
- Problemas de localização de ficheiros diagnosticados.
- Identificada a causa raiz:
  - estrutura incorreta + naming inconsistente
- Plano claro para reorganização do projeto.
- Base estabelecida para modularização do software.

#### Lições aprendidas
- `git fetch` não atualiza ficheiros locais (necessário `git pull`).
- A estrutura do repositório é tão importante como o código.
- Espaços em nomes de diretórios criam fricção significativa.
- Pequenos erros de naming (typos) escalam rapidamente em sistemas reais.
- O Git não protege contra má organização — apenas versiona o estado atual.
- Debug de sistemas reais depende de inspeção direta (ls, find, pwd).
- AI não substitui visibilidade sobre o sistema real.
- Integração (filesystem + Git + código) é mais difícil que programação isolada.

#### Próximo passo
- Eliminar estrutura duplicada (remover rasberrypi manual).
- Renomear corretamente:
  software/rasberry pi → raspberrypi
- Remover pasta software após migração.
- Criar estrutura final:
  - raspberrypi/comms
  - raspberrypi/control
  - raspberrypi/logging
- Mover serial_link.py para raspberrypi/comms/.
- Validar execução do módulo de comunicação isoladamente.
- Fazer commit da nova estrutura limpa.
- Iniciar implementação de main.py.
- Integrar modelo throttle + steering.

### 2026-07-19

#### Trabalho realizado
- Estudo dedicado do centro de gravidade e da distribuição de peso (documento SAILSAFE_estudo_CG_distribuicao_peso_v1), com orçamento de massas por componente (posições x/z), hidrostática integrada da geometria v5 e comparação de quatro configurações.
- Quantificação do problema na configuração v5: pilha placa base → caixa de baterias → caixa IP66 com topo a ≈385 mm e z_G ≈ 142 mm (≈105 mm acima da linha de água; calado estático ≈37 mm).
- Avaliação das opções: B1 (pilha pousada no convés, −8 mm), B2 (caixa suspensa entre travessas, −24 mm), A (duas baterias alojadas nos cascos, −33 mm) e C (combinada, −42 mm teóricos).
- Cálculo do lastro equivalente: igualar a opção C com chumbo no fundo exigiria ≈2,7 kg (+46 % de massa, +19 % de área molhada); lastro rejeitado.
- Revisão da arquitetura elétrica para três circuitos independentes, sem cabos de potência a atravessar a ponte: por casco, LiPo 5000 → fusível 40 A → loop key XT90-S → ESC → waterjet; na caixa IP66, LiPo 2200 dedicada → fusível/interruptor → DC-DC 5 V → Raspberry Pi + ESP32 + sensores.
- Definição da estratégia de comunicação: Wi-Fi do Pi para desenvolvimento; recetor ExpressLRS 868 MHz (UART/CRSF) como elo de segurança planeado, com canal de três posições desarmado / autónomo / recall; LoRa/4G apenas como evolução posterior.
- Definição das regras de recall/RTH: na Fase 1, recall = paragem dos motores; na Fase 2, recall = Return-To-Home com posição de casa gravada no momento de armar, recusa de arming sem fix GPS e station-keeping à chegada; perda de ligação executa a mesma ação do recall.
- Atualização do documento principal de arquitetura de v1.10 para v1.11: nova secção 20, tabelas vivas (REQ, energia 5.2, BOM, Apêndice B), OPEN-003 fechado e OPEN-006/OPEN-008 atualizados.
- Geração do modelo CAD v6 em STEP (25 sólidos nomeados: cascos com alojamentos escavados, travessas, longarinas, escotilhas, baterias, caixa IP66, calços, transom inserts e waterjets).
- Verificação geométrica 3D com identificação de dois conflitos que o estudo em vista lateral não apanhou: o túnel entre cascos tem 118 mm e a caixa IP66 tem 155 mm de largura (a caixa não pode descer abaixo do convés); e o vão T1–T2 da v5 (133 mm) não recebe nem os alojamentos (165 mm) nem a caixa (204 mm).
- Consolidação do layout v6: T2 reposicionada para X = 485 (vão T1–T2 de 217,5 mm); alojamentos com interior 165×62, centros X = 341 e Y = ±123, fundo interior a z = 45; caixa IP66 pousada em quatro calços de 6 mm ao nível do convés (fundo a z = 152), retida por ripas nas faces de T1/T2; longarinas de convés divididas em dois troços por casco (interrompidas nas escotilhas).
- Recalculo com as cotas finais: z_G ≈ 107 mm (−35 mm vs v5), massa estimada ≈6,2 kg, calado ≈39 mm, x_G ≈ 474 vs LCB ≈ 456 (ligeiro caimento à popa, favorável à alimentação dos jatos).
- Emissão da blueprint madeira v6 (3 folhas: vistas de conjunto, lista de corte revista e detalhes dos alojamentos e do apoio da caixa), em substituição da folha v5.
- Definição prática do GND comum na nova topologia: referência exclusivamente pelos fios de GND das fichas servo dos ESCs até ao ESP32, num único ponto na caixa IP66; sense de tensão das duas baterias de propulsão por fio único de positivo com resistência de ≈10 kΩ na origem e divisor junto ao ADS1015.
- Definição construtiva das loop keys: fêmea XT90-S em série no positivo (ambos os fios da tomada são positivo), chave em macho com pinos em ponte de 12 AWG, montada em poço recortado no convés entre a escotilha e o ESC, com cordão e boia; fusível dentro do alojamento, junto à bateria.
- Definição da sequência de operação: eletrónica primeiro (ESP32 a emitir neutro), só depois inserir as chaves; desarme pela ordem inversa.

#### Decisões técnicas
- Adotada a opção C revista (v6) como arquitetura mecânica: duas baterias de propulsão alojadas nos cascos, eliminação da caixa de baterias e da placa base (peças 3–9 da lista de corte) e caixa IP66 ao nível do convés.
- Rejeitado o uso de lastro para baixar o centro de gravidade; reservados apenas 50–100 g para acerto fino do caimento após a pesagem real.
- Adotada a topologia de três circuitos elétricos independentes; a ligação em estrela entre negativos definida a 2026-07-11 fica sem efeito, substituída pela referência por GND de sinal.
- Adotados dois loop keys (um por casco) como corte manual, substituindo o loop key único na distribuição central; fusível principal de 100 A e bus bars eliminados (proteção por fusível de 40 A junto a cada bateria).
- Rejeitado o corte de energia por rádio com relé ou MOSFET no caminho de potência: num barco autónomo, o corte remoto correto atua no sinal (STOP/recall por software), porque um corte de energia em perda de ligação impediria o próprio RTH; interruptor de estado sólido comandado pelo ESP32 registado apenas como upgrade opcional futuro.
- Ligar o sense de tensão a jusante da tomada do loop, de modo a que a mesma medição indique também o estado armado/desarmado de cada casco; o modo autónomo deverá recusar arming com um casco desarmado.
- Manter as regras LiPo (18.4) estendidas aos alojamentos: forro de contraplacado selado (sem contacto do LiPo com o XPS), respiro no rebordo da escotilha, carregamento sempre fora do barco — agora com três baterias.
- TEST-011 passa a ser executado nos dois ramos de propulsão (remoção e inserção de cada chave, com verificação de ausência de movimento durante o arming).

#### Problemas / limitações
- Os ficheiros de arquitetura originais não estavam disponíveis na primeira sessão de análise; o estudo partiu da folha blueprint v5 e as massas da eletrónica são estimativas assinaladas, a substituir por pesagens reais.
- Erratas identificadas no estudo de CG entretanto emitido: a profundidade do alojamento é de 101 mm desde o convés (fundo a z = 45; onde se lê 55 mm) e a posição ótima teórica das baterias (x ≈ 270) não é construível — as restrições geométricas fixam x = 341.
- O z_G real da v6 (≈107 mm) é 7 mm pior do que o ótimo teórico da opção C (≈100 mm), por a caixa IP66 não poder descer abaixo do convés.
- A segunda LiPo 5000, as loop keys XT90-S, o recetor ELRS e o multímetro fiável continuam por adquirir; todos os valores de massa, calado e trim permanecem "estimados", não "validados".
- A descarga assimétrica das duas baterias de propulsão passa a ser um modo de degradação próprio da nova topologia; mitigação por saída com cargas iguais e compensação de trim por software, pendente de validação física.

#### Resultado do dia
- Arquitetura mecânica e elétrica revista e fechada como SAILSAFE Architecture v1.11, com cotas finais na blueprint madeira v6 e no modelo SAILSAFE_concept_v6.step.
- Centro de gravidade reduzido de ≈142 para ≈107 mm (−25 %) sem lastro, com trim longitudinal dentro do alvo e autonomia duplicada pela segunda bateria.
- Cadeia de segurança clarificada em três camadas: física (loop keys por casco), lógica (arming/recall por software e, futuramente, ELRS) e automática (failsafe por timeout e watchdog).
- Conjunto de documentos coerente entre si: estudo de CG, documento de arquitetura v1.11, blueprint v6 e STEP v6.

#### Lições aprendidas
- Um estudo em vista lateral não substitui a verificação geométrica 3D: dois conflitos de montagem (largura do túnel e vãos entre travessas) só apareceram ao modelar o conjunto.
- Mover massa para baixo é muito mais eficiente do que acrescentar lastro; o lastro paga-se em calado, área molhada e autonomia.
- Num sistema autónomo, o kill remoto pertence à camada de sinal, não à de potência: cortar energia à distância destruiria a própria capacidade de o barco voltar.
- Separar circuitos elimina classes inteiras de falhas (brownout do Pi, paralelo de baterias), mas cria modos novos (descarga assimétrica) que têm de ser monitorizados.
- O ótimo teórico de um cálculo deve ser sempre confrontado com as restrições construtivas antes de entrar na documentação.

#### Próximo passo
- Pesar todos os componentes reais (waterjets, ESCs, caixa IP66 equipada, baterias) e recalcular z_G e x_G com as fórmulas do estudo de CG antes de qualquer corte.
- Fazer a disposição à escala real no vão T1–T2 (escotilhas + caixa) para confirmar as folgas de 3 e 3,5 mm.
- Adquirir a segunda LiPo 5000, as loop keys XT90-S (fêmeas + machos para as chaves e uma sobresselente), o divisor de tensão e o multímetro.
- Atualizar o esquema elétrico KiCad para a topologia de três circuitos.
- Prosseguir o plano de software de 2026-07-17 (máquina de estados, logging, heading hold com fontes simuladas), agora com o estado armado/desarmado por casco lido pelo sense.

### 2026-07-20

#### Trabalho realizado
- Reescrita do `serial_link.py`: de script de teste (comando fixo 10/10 em loop) para classe reutilizável `SerialLink`:
  - nenhuma ação ao ser importado; nunca envia comandos por iniciativa própria;
  - `connect()` devolve True/False em vez de lançar exceção com o ESP32 ausente;
  - tratamento de exceções em escrita/leitura e STOP (0/0) garantido no fecho da porta;
  - protocolo textual `L: x R: y\n` mantido intacto.
- Teste do módulo com o ESP32 desligado: aviso limpo e saída sem traceback (cenário "ESP32 ausente sem crash" validado).
- Commit e push da alteração; upstream da branch develop configurado no Raspberry Pi.
- Correção da localização do `main.py`: movido de `software/` para `software/raspberry_pi/` com `git mv`.
- Reescrita do `main.py` para integrar o `SerialLink`:
  - abre a ligação série se o ESP32 existir e escuta telemetria;
  - tentativa de religação automática a cada 10 s;
  - mantém-se em DISARMED — nunca envia comandos de propulsão;
  - STOP + fecho da porta garantidos ao sair (SIGINT/SIGTERM).
- Teste do `main.py` sem ESP32: arranque limpo, tolerância à ausência da porta e encerramento seguro confirmados.
- Primeira ligação física do ESP32 ao Raspberry Pi nesta fase: deteção em `/dev/ttyUSB0`.
- Execução do `main.py` com o ESP32 ligado: ligação série ativa e encerramento limpo.
- Validação da comunicação bidirecional com comando STOP (0/0):
  - resposta do ESP32: `Left: 0% -> 1000 us | Right: 0% -> 1000 us`;
  - failsafe do firmware confirmado em condições reais (`FAILSAFE ATIVO - motores parados` após comando isolado).

#### Decisões técnicas
- O `serial_link.py` passa a ser um módulo passivo: quem decide o que enviar é o `main.py`; o único valor por defeito é o STOP.
- O `main.py` permanece DISARMED nesta fase; a validação com hardware foi feita apenas com escuta e STOP, sem comandos de propulsão.
- Testes realizados com o ESP32 alimentado exclusivamente por USB, sem potência aos motores.
- Confirmada implicação de design para a fase seguinte: o modo ARMED terá de enviar comandos periódicos (heartbeat), caso contrário o failsafe do ESP32 corta os motores.

#### Problemas / limitações
- ESP32 inicialmente ligado à porta USB-C do Raspberry Pi (entrada de alimentação, não porta de dados) — sem deteção; resolvido ao mudar para uma porta USB-A.
- O firmware do ESP32 não envia telemetria por iniciativa própria; responde apenas a comandos recebidos.
- Porta série ainda fixa em `/dev/ttyUSB0`, sem udev rule (pendente de fase anterior).
- Eco do terminal ao colar heredocs longos dificulta a confirmação visual; a validação passou a ser feita por execução (um ficheiro truncado daria `SyntaxError`).

#### Resultado do dia
- Cadeia de comunicação Raspberry Pi ↔ ESP32 validada ponta a ponta com o novo código modular.
- Failsafe do ESP32 confirmado com hardware real, como segunda camada de segurança independente do Pi.
- Dois commits publicados na branch develop: refactor do `serial_link.py` e integração no `main.py`.

#### Próximo passo
- Implementar a máquina de estados DISARMED/ARMED no `main.py`, com heartbeat periódico e transições explícitas e seguras entre estados.

### 2026-07-21

#### Trabalho realizado
- Implementada máquina de estados mínima DISARMED ↔ ARMED no `main.py`, com controlo por teclado em bancada (a=ARM, d=DISARM, s=STOP, q=sair).
- Adicionado heartbeat a 5 Hz no estado ARMED (comando 0/0), para manter o failsafe do ESP32 satisfeito sem mover os motores.
- Garantido arranque sempre em DISARMED; rejeição de ARM sem ligação série; STOP com prioridade absoluta; regresso/perda da ligação série nunca arma sozinho.
- Criado o módulo de logging `telemetry/logger.py` (classe `SessionLogger`): um ficheiro `session_<timestamp>.csv` por arranque, colunas `timestamp, event, state, detail`, escrita com flush imediato.
- Adicionado `logs/` ao `.gitignore` (dados de execução, não versionados).
- Integrado o `SessionLogger` no `main.py`: registo de BOOT, SERIAL, STATE, TX, RX, STOP, WARN e SHUTDOWN.
- Validação com hardware real (ESP32 por USB, sem potência aos motores): máquina de estados e logging testados ponta a ponta.
- Três commits publicados na branch `develop` (`9e9ede9`, `b04e118`, `20797b8`).

#### Decisões técnicas
- Heartbeat fixado em 5 Hz (200 ms), com folga larga sobre o timeout do failsafe do ESP32.
- No estado ARMED, o heartbeat envia 0/0 por agora, por ainda não existir fonte de propulsão; o objetivo desta fase foi validar o mecanismo, não mover motores.
- Logging definido com esquema genérico (`event`/`state`/`detail`) para acomodar futuros campos de heading, GPS e waypoints sem quebrar o formato.
- Logs mantidos dentro do projeto (`software/raspberry_pi/logs/`), fora do controlo de versões.
- Adotar daqui em diante o fluxo editar-no-PC → `git push` → `git pull` no Pi, abandonando a edição direta no Pi.

#### Problemas / limitações
- O terminal/SSH do Pi corrompeu repetidamente colagens de várias linhas (perda e substituição de caracteres), impedindo colar ficheiros via heredoc. Contornado com transferência em base64 partida em pedaços pequenos e verificada por hash — solução funcional mas lenta, a eliminar com o fluxo Git.
- O parser não-bloqueante ocasionalmente lê meia linha por ciclo, partindo mensagens do ESP32 em dois registos (ex.: `Right: 0%` e `-> 1000 us` separados); conteúdo correto, apresentação por limpar.
- Surge um `COMANDO INVALIDO` inicial (lixo no buffer quando a porta abre e o ESP32 reinicia); inofensivo, motores parados.
- Heartbeat a 0/0 apenas; sem controlo de propulsão real até existir loop key e cadeia de potência protegida.

#### Resultado do dia
- Máquina de estados DISARMED/ARMED operacional e validada com hardware, com as duas camadas de segurança (heartbeat + failsafe do ESP32) confirmadas a trabalhar em conjunto.
- Sistema de logging por sessão funcional, com timestamps ao milissegundo.
- Timeout do failsafe do ESP32 medido a partir dos logs: ≈ 1,1 s após o último comando — margem confortável face aos 200 ms do heartbeat.
- Cadência do heartbeat confirmada nos dados (~204 ms entre envios).

#### Lições aprendidas
- O logging paga-se sozinho: permitiu medir o timeout do failsafe e a cadência do heartbeat sem instrumentação extra.
- Uma máquina de estados só é segura se o estado seguro for o de arranque e se nenhum evento (perda/regresso de ligação) provocar movimento automático.
- Colar código via terminal não é fluxo de trabalho; a fonte de verdade em Git com `git pull` no destino evita corrupção e retrabalho.

#### Próximo passo
- Migrar o fluxo de desenvolvimento para editar no PC e sincronizar por `git pull` no Pi.
- Limpar o parser das linhas partidas e filtrar o `COMANDO INVALIDO` do arranque.
- Iniciar o heading hold com fontes de heading e posição simuladas (controlador proporcional), conforme o plano de 2026-07-17.
- Adiar a energização dos ESCs até à chegada da loop key e da cadeia de potência protegida por fusíveis.

### 2026-07-22

#### Trabalho realizado
- Adotado o fluxo de trabalho baseado em Git: clonado o repositório no PC (via HTTPS), passando o desenvolvimento a editar-no-PC -> commit/push -> git pull no Pi, eliminando a transferência de código por base64 no terminal.
- Corrigido o parser série do lado do Pi: read_line passa a acumular bytes num buffer interno e só devolve linhas completas; connect faz reset_input_buffer para descartar o lixo de arranque do ESP32 (fim do COMANDO INVALIDO inicial).
- Implementada a lógica de controlo de rumo em control/heading.py: normalize_angle (intervalo -180..+180), heading_error (evita o salto 359<->0) e HeadingController proporcional com saturação.
- Implementado o mixer de propulsão em control/mixer.py: converte throttle + steer em comandos L/R, com saturação.
- Criada a fonte de heading sintética em control/sources.py (SimulatedHeading) e um ciclo fechado de simulação controlador -> mixer -> barco.
- Criados testes automáticos sem hardware (tests/test_heading.py, tests/test_mixer.py), incluindo o caso crítico do salto angular.
- Integrado o modo NAV na máquina de estados do main.py: em NAV, o heading hold gera comandos L/R (limitados a 30%) enviados ao ESP32, com a malha fechada pelo simulador; regista heading e comandos no CSV.
- Validação com hardware real na comunicação: NAV testado com o ESP32 ligado, com o rumo simulado a convergir de 0 para o alvo de 90 graus em ~7 s e os motores a estabilizarem em 20/20. O ESP32 aceitou todos os comandos.
- Auditoria de segredos ao repositório e ao histórico (limpa: sem chaves, passwords, IPs ou emails privados); adicionada LICENSE (MIT) com aviso de segurança.
- Fusão develop -> main; histórico reescrito para uniformizar o autor de todos os commits como Gonçalo Silva; push forçado e re-sincronização do Pi.
- Implementada a navegação por waypoints em control/navigation.py (haversine_m, bearing_deg, WaypointNav) com SimulatedBoat (posição + rumo) em control/sources.py e tests/test_navigation.py; ciclo fechado simulado a percorrer dois waypoints (100 m Norte + 100 m Este) validado no PC e no Pi.

#### Decisões técnicas
- Manter o desenvolvimento do heading hold em simulação: sem motores a malha não se fecha fisicamente; a fonte de dados fica separada da lógica para trocar o simulado pelo BNO055 real sem alterar o controlador.
- Reconciliar o teto de segurança: o Pi limita os comandos de NAV a 30%, alinhando com o PERCENT_MAX_SAFE imposto pelo ESP32.
- Manter o controlador proporcional puro (sem I/D), conforme decidido a 2026-07-17.
- Descartado o uso de um LLM para previsão de eficiência/consumo: é um problema de regressão numérica com estrutura física (modelo físico de energia + regressão sobre os logs + medição de corrente/tensão), não de linguagem.
- Passar a trabalhar diretamente na branch main (projeto solo; a develop cumpriu o seu papel durante a reestruturação).

#### Problemas / limitações
- Falha de importação no Pi por módulos escritos mas não commitados antes de se construir por cima deles; lição: commitar cada peça antes de depender dela.
- O ciclo fechado do NAV é sintético; a afinação real do controlador só será possível com motores e testes na água.
- O BNO055 ainda não está integrado nem calibrado; waypoints pendentes de GPS real.

#### Resultado do dia
- Fluxo de desenvolvimento profissional estabelecido (Git como fonte de verdade).
- MVP de navegação em simulação: heading hold + waypoints, integrado na máquina de estados e validado com comunicação real ao ESP32.
- Repositório público em ordem: main como branch principal, LICENSE, autoria uniformizada.

#### Lições aprendidas
- Separar fontes de dados da lógica de controlo permite desenvolver navegação sem sensores/atuadores reais.
- No fluxo Git, dependências têm de ser commitadas antes do código que as usa.
- Escolher a ferramenta pelo problema: previsão física pede modelo físico e dados medidos, não um LLM.

#### Próximo passo
- Ligar o WaypointNav ao modo NAV do main.py (bearing do waypoint como alvo do heading hold).
- Preparar a interface RealHeading para o BNO055 (teste de rodar à mão, sem motores).
- Adiar a energização dos ESCs e motores até à chegada da loop key e da cadeia de potência protegida por fusíveis.

### 2026-07-23

#### Trabalho realizado
- Revisão mecânica maior: produzido o blueprint em madeira v6.1 (5 folhas). Baterias alojadas dentro dos cascos (X=341, Y=+/-123, fundo z=45, ~6 mm acima da linha de água), eliminando a placa base e a caixa central de baterias. Caixa IP66 (204x155) pousada ao nível do convés (fundo z=152, topo z=252), com calços e ripas de retenção aparafusadas a T1/T2. Travessa T2 recolocada em X=485. Escotilhas 185x85 com reforço perimetral, junta de neopreno 3 mm, 6 insertos M4 de latão e parafusos de orelhas em nylon; compartimento não hermético com respiro (regra 18.4). Pele em contraplacado marítimo 3 mm; proa (X 0-200) laminada em fibra de vidro + epóxi; lista de materiais consolidada (folha 5).
- Correção geométrica da v6 verificada em 3D: o túnel entre cascos (118 mm) é mais estreito do que a caixa IP66 (155 mm), impedindo a caixa de descer abaixo do convés.
- Definidas as sequências de serviço das baterias (retirar chaves -> abrir escotilhas -> extração pela patilha -> carregar fora do barco) e de montagem (fechar tampas -> ligar eletrónica -> esperar neutro do ESP32 -> inserir chaves).
- Pesquisa sobre o kill-switch remoto: avaliada e descartada a hipótese de usar uma antena DVB TW25.
- Definição da arquitetura de logging e armazenamento de dados a bordo e em terra.
- Enquadramento do projeto como campo de treino para a cadeira de Algoritmos e Estruturas de Dados (AED).
- Análise de âmbito para futura câmara e sensores.

#### Decisões técnicas
- Kill-switch remoto: a antena DVB TW25 não serve (antena de receção de TV, banda UHF de broadcast; não transmite nem corta). A solução é um sistema RC de hobby (2,4 GHz) com failsafe do recetor a cortar a potência, ou um link LoRa com heartbeat; a antena tem de ser da banda do rádio escolhido. Mantém-se a loop key XT90 como corte manual temporário.
- Logging a bordo: ficheiro sequencial (CSV ou registos binários de tamanho fixo) com flush regular, sobre um buffer circular em array estático - sem base de dados e sem malloc em ciclo de tempo real. SQLite fica reservado para análise em terra.
- Confirmado que a navegação por waypoints é geometria + controlo (haversine, bearing, cross-track, PID de rumo), não algoritmos de grafos; pathfinding só entraria para zonas proibidas ou cobertura de área.
- Usar o projeto como aplicação prática da AED: buffer circular para amostras a alta frequência, lista ligada para a lista de waypoints da missão, structs + ponteiros para os registos.
- Câmara e sensores adiados para depois do núcleo. Se adicionada, a câmara grava a bordo e analisa-se em terra (sincronização vídeo-logs por timestamp; metadados em SQLite). Preferir geofencing por GPS à deteção de obstáculos por sensores.

#### Problemas / limitações
- PIR não funciona na água; ultrassons e ToF/laser comportam-se mal com ondas e reflexos; deteção de obstáculos em superfície é um problema difícil (câmara + visão), fora do âmbito atual.
- Processamento de vídeo em tempo real no Pi é proibitivo em CPU e consumo.
- Kill-switch remoto continua por resolver em hardware.

#### Resultado do dia
- Arquitetura mecânica consolidada na v6.1, com as baterias nos cascos e simplificação estrutural.
- Estratégia de dados clara: sequencial + buffer circular a bordo, SQLite em terra.
- Caminho do kill-switch remoto esclarecido (RC/LoRa, não antena de TV).

#### Lições aprendidas
- A estrutura de dados certa depende do padrão de acesso: array circular para fluxo contínuo, lista ligada para coleções pequenas e ordenadas editadas manualmente.
- malloc em ciclo de tempo real evita-se por princípio.
- Trabalho de bancada de alto valor sem ESCs nem motores: gravar dados reais do IMU/GPS e afinar o controlo contra dados gravados.

#### Próximo passo
- Ligar o WaypointNav ao modo NAV do main.py, fechando a navegação autónoma completa em simulação.
- Implementar o buffer circular de logging como exercício de AED.
- Definir o sistema de rádio para o kill-switch remoto (RC 2,4 GHz vs LoRa) e a cadeia de corte.
- Manter a proibição de energizar ESCs/motores até existir corte físico dimensionado.

### 2026-07-24

#### Trabalho realizado
- Adicionado `hardware/mechanical/SAILSAFE_concept_v6_2.step`: o modelo v6 (exportação real do Fusion) com aberturas de acesso às baterias cortadas nos dois cascos, para extração vertical dos packs 5000.
- Recorte por casco: janela retangular X 258.5-423.5, Y +/-90.5 a +/-155.5, do assento da bateria (z=45) através do convés (z=146). Deixa lábio de ~10 mm dentro da pegada da escotilha (185x85) para a tampa assentar; folga de 5 mm em X e ~8 mm em Y à volta do pack (155x48x35). Livre entre T1 e T2 (sem travessa por cima).
- Verificado programaticamente (OpenCASCADE): 25 componentes preservados com nomes originais; apenas casco_direito e casco_esquerdo alterados (-50 cm3 cada); janela do convés confirmada aberta (0 cm3 de material residual). Restantes 23 corpos idênticos em volume e bounding box.

#### Notas / limitações
- O corte foi feito por operação booleana sobre a geometria exportada; o ficheiro foi reescrito pelo kernel OpenCASCADE (cabeçalho deixa de ser "Autodesk Translation Framework") e não traz histórico paramétrico. Para versão 100% limpa com timeline, replicar o recorte no Fusion com as cotas acima e reexportar STEP.
- Mantido o `SAILSAFE_concept_v6_1.step` (esboço de caixas) no repo; substituição/remoção fica para decisão separada.

#### Efeito no CG
- As duas baterias 5000 (baixas, z 45-80, simétricas em Y, centradas em X~341) são as maiores massas removíveis. Retirá-las não induz adorno lateral (simetria) mas sobe o CG e desloca-o ligeiramente para a ré; reverificar trim com baterias fora.

#### Próximo passo
- Ligar o WaypointNav ao modo NAV do main.py (navegação autónoma completa em simulação).
- Confirmar as cotas de acesso à bateria contra o blueprint v6.1 e, se necessário, replicar o recorte no Fusion para o modelo mestre.

### 2026-07-25

(Sessão da noite de 25 para 26; os commits correspondentes ficam com data de 26.)

#### Trabalho realizado
- Revisão do esquema elétrico v1.11 durante a passagem do desenho para KiCad. Detetado um erro de dimensionamento no sense de tensão: com o divisor 10k/2k2 (k=0.180328), uma LiPo 3S carregada dá 2.272 V à entrada do ADS1015, acima do FSR por omissão de ±2.048 V. O limite de saturação referido à bateria é 11.36 V, ou seja toda a zona útil de descarga (12.6 → 11.4 V) lia saturado; a bateria pareceria cheia até já ir a meio da descarga.
- Correção adotada sem alterar hardware: PGA do ADS1015 em ±4.096 V (GAIN_ONE). Fundo de escala passa a 22.71 V de bateria, com resolução de 11.09 mV (3.70 mV por célula).
- Escrita a especificação `hardware/electrical/SAILSAFE_sense_v1_11_1.md`: tabelas de conversão, análise de erro, filtro, reserva de canais para corrente, alterações a fazer no KiCad e plano de verificação em bancada.
- Fechada a navegação autónoma em simulação: o modo NAV do `main.py` deixa de manter um rumo fixo de 90° e passa a seguir o bearing do waypoint atual, dado pelo WaypointNav. Era o ponto 1 da lista de próximos passos e o último item em falta do MVP de software.
- `main.py`: `SimulatedHeading` substituído por `SimulatedBoat` (o modo NAV precisa de posição, não só de rumo); acrescentada a missão de demonstração (dois waypoints, 40 m a Norte e depois 40 m a Este) e o raio de chegada de 4 m; removida a constante NAV_TARGET.
- Extraída a função `nav_step()`, um passo de navegação sem qualquer I/O: posição → bearing → heading hold → mixer → barco.
- Novo `tests/test_nav_mode.py` com 8 testes. Passam os 18 testes do projeto (heading 3, mixer 4, navigation 3, nav_mode 8).
- Verificado o ciclo fechado a 5 Hz: missão concluída em 619 passos (~124 s), com a viragem para o segundo waypoint a convergir em ~20 s.

#### Decisões técnicas
- Manter o divisor 10k/2k2 em vez de apertar para 10k/1k5: a resolução extra não se traduz em precisão real (o erro dominante são os resistores, não o ADC) e mantém margem para 4S — 16.8 V dá 3.03 V, dentro do FSR e do máximo absoluto de entrada (VDD+0.3 = 5.3 V).
- Resistores de sense especificados a 1 % metal film. A 5 % o erro seria ±1.07 V a 12.6 V, mais de um terço da janela útil de descarga.
- Calibração de um ponto por canal em software (multímetro → fator de escala em configuração), porque mesmo a 1 % o erro (±0.21 V) é ~19x pior que a resolução do ADC.
- Condensador de 1 µF em paralelo com o resistor inferior de cada divisor (fc = 88 Hz com Rsrc = 1.80 k), para rejeitar o ruído de comutação do ESC.
- Reservados A2/A3 do ADS1015 para ISENSE_E / ISENSE_D (ACS758LCB-050U, Hall isolado, 60 mV/A, 33 mA por conta). Sem corrente não há modelo de autonomia possível; os quatro canais ficam exatamente preenchidos.
- Fim de missão vai a DISARMED com `stop_motors()` explícito, em vez de ficar em ARMED. Zera a propulsão de forma ativa em vez de depender do timeout do failsafe, e não deixa o barco armado à espera; coerente com o princípio de estado seguro por omissão.
- Ao entrar em NAV a missão é recriada do início, a partir da posição atual do barco. Carregar em `n` reinicia sempre a missão, sem estado escondido de execuções anteriores.
- `nav_step()` devolve um namedtuple (left, right, bearing, dist, done, lat, lon), e a posição devolvida é a do instante da decisão e não a de depois do movimento, para o log registar aquilo sobre que o controlador decidiu.
- Testes incluem invariantes de segurança e não só convergência: comandos sempre em [0, 30] (sem marcha atrás, abaixo do teto do ESP32), missão concluída nunca devolve propulsão residual, e coerência entre NAV_THROTTLE, SAFE_MAX e o heartbeat face ao failsafe de ~1 s.

#### Problemas / limitações
- Com os quatro canais do ADS1015 ocupados não sobra entrada para monitorizar o próprio rail de 5 V. A saída do ACS758 é ratiométrica à sua alimentação e o ADS1015 mede contra referência interna, portanto oscilações do 5 V desviam a leitura de corrente. Compensação ratiométrica exigiria um segundo ADS1015 (endereço alternativo pelo pino ADDR).
- Liga-se ao pendente dos servos no rail de 5 V: se os servos ficarem nesse rail, os picos de corrente deles passam a contaminar também a leitura de corrente.
- Um dos testes falhou à primeira por erro do próprio teste (não registava a amostra de chegada ao último waypoint, dando 4.1 m contra um raio de 4.0 m). Corrigido no teste; a navegação estava certa.
- O modo NAV continua a exigir ligação série aberta para arrancar, por isso o ciclo principal completo não é testável sem ESP32; só `nav_step()` é que é. Limitação aceite, não defeito.
- Nada do sense está verificado em hardware: o ADS1015 e os sensores de corrente ainda não existem na bancada.
- Tudo na navegação continua sintético: sem GPS, sem BNO055, sem motores. O que está validado é a lógica, não o comportamento do barco na água.

#### Resultado do dia
- MVP de software concluído dentro do prazo que o próprio log tinha fixado para 2026-07-26: máquina de estados, heading hold, navegação por waypoints, logging e testes, tudo validado em simulação com comunicação real ao ESP32.
- Corrigido um erro de dimensionamento do sense que teria inutilizado a leitura de bateria sem dar sinal de avaria — leria sempre um valor plausível, só que errado.

#### Lições aprendidas
- Verificar sempre a gama de entrada de um ADC contra a configuração por omissão, e não só contra o máximo absoluto. O circuito estava eletricamente seguro e mesmo assim inútil: a saturação não queima nada, só mente.
- Num divisor resistivo, o erro dominante costuma ser a tolerância dos resistores e não a resolução do conversor. Vale mais gastar em 1 % e calibrar um ponto do que em bits.
- Um teste que falha não é necessariamente um defeito no código; desta vez o erro estava no próprio teste. Convém ler o que o teste mede antes de mexer naquilo que ele testa.
- Extrair a lógica para uma função sem I/O (`nav_step`) foi o que tornou o modo NAV testável sem hardware. O que depende de portas série e ficheiros não se consegue testar; o que é cálculo puro, sim.
- Começar a perceber o código já escrito antes de acrescentar camadas por cima. Definida a ordem de leitura de baixo para cima: mixer → heading → navigation → sources → logger/serial → main → firmware do ESP32.

#### Próximo passo
- Interface `RealHeading` para o BNO055 (teste de rodar à mão, sem motores), substituindo a fonte sintética de rumo sem tocar no controlador.
- Buffer circular de logging como exercício de AED.
- Aplicar no KiCad as alterações de sense: tolerância 1 % em R1..R4, condensadores de 1 µF nos dois divisores, nós ISENSE_E/ISENSE_D em A2/A3, e nota do PGA junto de U4.
- Exportar o STEP do Fusion para substituir o `SAILSAFE_concept_v6_1.step` (esboço de caixas) e decidir a sua remoção.
- Kill-switch remoto (RC 2,4 GHz vs LoRa) e cadeia de corte — continua a ser o bloqueio para qualquer ensaio na água.

### 2026-07-26

#### Trabalho realizado
- Modelo de conceito `SAILSAFE_concept_v6_3.step`: o v6_2 tinha só estrutura, baterias e waterjets. Acrescentados 16 sólidos com os componentes que faltavam — eletrónica dentro da caixa IP66, ESCs e motores nos cascos.
- Dentro da caixa (interior útil X 254,5..453,5 · Y ±75 · Z 154,5..252): `raspberry_pi_4` (85×56×20, sobre espaçadores de 8 mm), `esp32_devkit` (55×28×13), `bno055_imu` (20×27×5) sobre `suporte_BNO055`, `gps_modulo` (25×25×8) sobre `suporte_GPS`, `conversor_DCDC_5V` (65×35×20), `distribuidor_fusiveis` (60×40×30), `sensor_corrente` (31×13×15) e `ads1015` (25×18×4).
- Nos cascos: `esc_dir`/`esc_esq` (80×40×30) sob a longarina de ré, e `motor_dir`/`motor_esq` (cilindro Ø36×70) coaxiais com o waterjet, ligados por `veio_motor_*` (Ø5×20) até à admissão.
- `bateria_pi_2200` redimensionada de 120×60×30 (valor inventado) para 105×35×25 (LiPo 3S 2200 mAh real) e movida para a antepara de vante, atravessada — no sítio antigo colidia com o Raspberry Pi.
- Escrito `hardware/mechanical/tools/build_concept_v6_3.py`, que gera o v6_3 a partir do v6_2. Até agora os STEP do repositório não tinham gerador versionado; a partir daqui o modelo de layout é reproduzível.
- Escritos `tools/verify_concept.py` (integridade referencial, colisões AABB, folgas, CG) e `tools/validate_occ.py` (BRepCheck_Analyzer sólido a sólido). Resultado: 0 referências mortas, 0 ids duplicados, 41/41 sólidos válidos, 0 colisões entre componentes.
- Escrito `tools/make_layout_svg.py` e gerado `SAILSAFE_layout_v6_3.svg`: vista de cima e vista lateral com legenda numerada, para rever o arranjo sem abrir CAD.

#### Decisões técnicas
- Não gerar B-rep de raiz. Sem kernel CAD garantido (CadQuery/OCP não instala de forma fiável), o gerador clona a topologia de dois sólidos já válidos do próprio ficheiro — `calco_IP66_1` para caixas e `waterjet_dir` para cilindros — e aplica-lhes uma transformação afim por eixo. Como os moldes estão alinhados aos eixos, a transformação preserva a validade, desde que as *pcurves* sejam reescaladas com os fatores dos eixos locais de cada superfície (para o cilindro, u é ângulo e não escala; v é distância axial e escala).
- GPS no topo e a vante, ~70 mm do Raspberry Pi. O Pi 4 é uma fonte conhecida de ruído perto de 1,5 GHz; encostar o módulo GPS ao Pi degrada a receção. O suporte tira-o também do plano dos cabos de potência.
- BNO055 sobre coluna, ao centro em Y e a meio do comprimento, longe da eletrónica de potência. Como é magnetómetro, interessa afastá-lo dos condutores de corrente elevada e das baterias.
- ESC a z 104..134, 2 mm abaixo da longarina de ré. A primeira tentativa (z 116..146, encostado ao convés) atravessava a longarina — apanhado pelo verificador de colisões, não a olho.
- Componentes modelados como envelopes com folga, não como modelos de fabricante. O objetivo é decidir arranjo e confirmar que cabe, não desenhar suportes.
- Manter as LiPo 4S 5000 mAh nos cascos (155×48×35 já era realista) em vez de as passar para a caixa: baixam o CG e libertam a caixa para a eletrónica.

#### Problemas / limitações
- CG estimado em X = 468 mm, ou seja 58 % do comprimento a contar da proa, com massa total ~11,6 kg. Está deslocado para ré: motores, waterjets, ESCs e transom insert somam ~2,5 kg concentrados no último quarto. Provoca trim de popa; a correção natural é passar as LiPo 5000 mAh para vante nos cascos, que é a massa maior e a mais fácil de mover.
- O `caixa_IP66` do modelo é um tabuleiro aberto (paredes de 2,5 mm, sem tampa). As folgas verificadas são ao interior do tabuleiro; a altura livre real fica menor quando houver tampa e vedante.
- A `cobertura_ESC_*` continua a ser um bloco maciço no modelo, por isso o ESC aparece "dentro" dela em corte. É limitação da representação, não do arranjo.
- Sem cablagem, bucins, suportes de motor nem furação. O veio motor–waterjet é um cilindro reto: não há acoplamento nem chumaceira modelados, e é aí que o alinhamento real vai doer.
- Todas as dimensões dos componentes que ainda não existem (ESC, motores, GPS) são valores típicos de catálogo. Quando as peças chegarem, medir e voltar a correr o gerador.

#### Resultado do dia
- O modelo de conceito passou a responder à pergunta que interessa antes de comprar: cabe tudo, e onde. Sobram ~68 mm à ré do Pi e ~45 mm à proa dentro da caixa, com o pior aperto em +X no distribuidor de fusíveis (5,5 mm).
- Ficou uma cadeia reprodutível: gerar → verificar colisões e folgas → validar sólidos → desenhar. Um erro de arranjo (ESC contra a longarina) foi apanhado por script e não por inspeção visual.

#### Lições aprendidas
- Um modelo de layout com colisões verificadas por script vale mais do que um render bonito. As duas colisões deste dia não se viam na vista de cima.
- Quando não há a ferramenta certa, clonar geometria já válida e transformá-la é mais seguro do que escrever B-rep à mão: herda-se a topologia correta e só há que acertar coordenadas.
- Um valor "provisório" num modelo (a bateria de 120×60×30) sobrevive muito para lá do provisório e depois choca com o resto. Vale a pena pôr dimensões reais assim que se souberem.

#### Próximo passo
- Passar as LiPo 5000 mAh para vante nos cascos e voltar a correr o cálculo de CG, com objetivo de 45–50 % do comprimento.
- Interface `RealHeading` para o BNO055 (teste de rodar à mão, sem motores).
- Buffer circular de logging como exercício de AED.
- Exportar o STEP do Fusion e decidir a remoção do `SAILSAFE_concept_v6_1.step`.
- Kill-switch remoto (RC 2,4 GHz vs LoRa) e cadeia de corte — continua a bloquear qualquer ensaio na água.

### 2026-07-26 (sessão 2 — apresentação e correções cruzadas)

#### Trabalho realizado
- Análise estruturada de todo o material do projeto (STEP v6_3, arquitetura v1.11, layout SVG), com assistência de IA, e relatório de Fase 0: confirmado vs. estimado vs. em falta, contradições entre documentos, e lista priorizada de melhorias visuais.
- Primeira versão do site do projeto: visualizador 3D interativo (three.js) com o modelo reconstruído a partir do STEP, toggles por subsistema, ficha técnica por componente ao clicar, corte longitudinal, linha de água ao calado derivado e vista explodida. Conteúdo bilingue PT/EN. Versão de ficheiro único (`website/SAILSAFE.html`) que abre por duplo clique, e versão modular preparada para GitHub Pages.
- Esquema elétrico v1.11 cruzado com o site e com a arquitetura: detetadas e corrigidas três divergências no conteúdo publicado.
- Modelo `SAILSAFE_concept_v6_4.step` gerado com o motor de clonagem do `build_concept_v6_3.py`: 50 sólidos novos que decompõem os envelopes em geometria reconhecível — Raspberry Pi 4 (13 sólidos: GPIO, USB, RJ45, SoC), ESP32 (8), GPS (4), BNO055 (3), waterjet com admissão/grelha/estator/tubeira/bocal orientável (7 por lado) e servo do bocal (4 por lado). Duto do waterjet da v6_2 reescalado para X 735..793 para dar lugar ao detalhe a jusante.
- `verify_concept.py` sobre o v6_4: primeira passagem acusou 19 colisões do detalhe contra o duto original; anatomia reorganizada até zero colisões. Envelope preservado (815×350×252). Uma colisão era real: o conector CSI contra a RAM do Pi — RAM deslocada em Y como na placa verdadeira.

#### Decisões técnicas
- O site marca cada valor com a proveniência (validado / estimado / derivado / em aberto), mantendo o estatuto que os números têm na documentação — nenhum valor de desempenho é apresentado como medição.
- Divergências fechadas a favor do esquema elétrico, por ser o documento mais recente: bateria da eletrónica é 2S 2200 (não 3S); arquitetura de três circuitos independentes sem fusível principal de 100 A nem bus bars (40 A por casco + 10 A eletrónica, nenhum cabo de potência atravessa a ponte); manobra combina diferencial com bocal orientável por servo (SRV_E/SRV_D) — marcada "em aberto" porque o firmware ainda só tem os dois ESCs.
- Componentes detalhados gerados a partir das cotas dos desenhos mecânicos públicos, não de CAD de terceiros — evita problemas de licença no repositório.

#### Problemas / limitações
- O `verify_concept.py` rebenta no cálculo de folgas com o v6_4 (procura os nomes antigos `raspberry_pi_4` etc., agora decompostos em `rpi4_*`); a verificação de colisões corre completa antes disso.
- O firmware não tem saídas de servo; o esquema tem M3/M4. Divergência registada, por resolver no código.

#### Resultado do dia
- Projeto passou a ter apresentação: relatório de análise, site interativo e modelo com componentes reconhecíveis, tudo coerente com a documentação e com as divergências documentais identificadas e corrigidas.

#### Lições aprendidas
- Cruzar o esquema elétrico com o documento-mãe apanhou três divergências que nenhum dos documentos denunciava sozinho. A validação entre documentos vale tanto como a validação dentro de cada um.
- O verificador de colisões voltou a pagar-se: 19 sobreposições na primeira passagem do detalhe, uma delas um erro real de posicionamento (CSI vs. RAM).

#### Próximo passo
- Adaptar o cálculo de folgas do `verify_concept.py` aos nomes decompostos do v6_4.
- Acrescentar as saídas SRV_E/SRV_D ao firmware do ESP32 ou reverter o esquema, para eliminar a divergência.

### 2026-07-27

#### Trabalho realizado
- Site reescrito como viagem imersiva: panorâmica equirectangular como céu esférico 360º em que a câmara roda de verdade, cinco capítulos guiados pelo scroll (navegação → jatos → casco → praia → interior), arrasto livre para olhar à volta e marcadores ancorados às peças 3D que abrem a ficha técnica de cada componente.
- No capítulo do interior, a caixa IP66, escotilhas e coberturas desvanecem para expor a eletrónica — transição de cenário (mar → areia) por crossfade entre panorâmicas com movimento de câmara.
- Pipeline HDR: escrito leitor de Radiance RGBE de raiz (o imageio colapsava para 8 bits) com tone mapping ACES e exposição automática pela mediana. Convertida uma HDRI CC0 de praia (Poly Haven, 4096×2048) e geradas duas cenas da mesma imagem — dia e fim de tarde (−2 EV, tom quente) — eliminando a panorâmica anterior de 1024 px e a foto com marca de água de origem desconhecida.
- Jato dos waterjets refeito três vezes até ficar aceitável: partículas soltas → núcleo aditivo (parecia uma lanterna) → tubo de água opaco com transmissão/clearcoat/IOR 1,33, dobrado por frame ao longo de parábola balística, com salpicos a nascer no ponto de impacto na água.
- Controlo do palco iterado com feedback de utilização: sensibilidade final ~3× a inicial, zoom por roda removido (roubava o scroll da página), câmara fica onde o utilizador a deixa, botão de repor vista.
- Rotação base do céu calculada analiticamente (R = −az − 2πu, com a água da enseada a u≈0,475 → 2,705 rad) para o barco flutuar na água da fotografia e não sobre a areia.

#### Decisões técnicas
- Sem geração de imagens disponível, a qualidade do fundo fica limitada à resolução da fonte: 4096 nativos na versão GitHub Pages, 2560 embutidos no ficheiro único (3,9 MB). HDRI de 8/16K do Poly Haven ou panorâmica própria de telemóvel como caminho de melhoria.
- Água sem blending aditivo em nenhum elemento — água reflete e transmite, não emite.

#### Problemas / limitações
- O jato ainda é uma aproximação (tubo + salpicos); não há simulação de fluido nem espuma de impacto persistente.
- O ambiente de teste não tem WebGL: a validação visual continua a depender de abrir o ficheiro no browser real.

#### Resultado do dia
- Site com movimento legível (é o cenário que passa), fundo fotográfico ao nível da fonte, jatos com comportamento de água e controlo de câmara utilizável. Onze iterações de ficheiro único até à v11.

#### Lições aprendidas
- Movimento sem referência visual não se lê: o barco "andava" mas o fundo fixo anulava a perceção. Rodar o cenário resolveu o que aumentar a velocidade não resolvia.
- Blending aditivo é para luz, não para água. O mesmo efeito com material físico (transmissão + clearcoat) muda a leitura por completo.
- Em UX de scroll, qualquer elemento que capture a roda do rato compete com a navegação da página — interação de câmara deve ficar no arrasto.

#### Próximo passo
- Panorâmica própria (rio) para substituir a HDRI genérica; conversor pronto em `website/hdr2jpg.py`.
- Publicar no GitHub Pages com as panorâmicas de 4096 externas.
- Fase 2 do interior: cablagem gerada a partir da netlist do KiCad e transições de câmara por subsistema.

### 2026-07-27 (sessão 2 — wash dos jatos, fundo e preparação de publicação)

#### Trabalho realizado
- Wash dos waterjets refeito a partir de fotografia de referência de uma embarcação a jato real: em vez de "tubo de água", espuma branca arejada em três camadas — cadeia de sprites de espuma ao longo da parábola balística do jato, planos de wash junto à superfície com textura a rolar no sentido do escoamento, e partículas de salpico no ponto de impacto. Tudo com blending normal (regra mantida: água não emite luz).
- Fundo fotográfico abandonado em definitivo. Duas tentativas de manter a foto fixa alinhada com a câmara 3D (deslocamento de `backgroundPosition` com o tilt; projeção do horizonte 3D sobre o da foto) falharam pela mesma razão de fundo: uma fotografia é um ponto de vista fixo e a câmara do palco é livre — qualquer rotação lê-se como "a água mexeu-se", não como "eu mexi-me".
- Substituído por gradiente CSS uniforme, como na primeira versão do site. Sem paralaxe não há nada que traia o movimento da câmara. Após teste, o céu branco inicial foi suavizado para azul-cinza (#a9c3d6 → #b9c9cd) por encandear.
- Mantida uma panorâmica pequena (92 kB) apenas como environment map, para os reflexos na água e no casco não morrerem com a saída da fotografia.
- Criado workflow de deploy no GitHub Actions (`.github/workflows/deploy-site.yml`): publica a pasta `website/` no GitHub Pages e só dispara quando há alterações em `website/**`.
- Rebuild final do ficheiro único `SAILSAFE.html` (1,72 MB) e sincronização de todos os ficheiros para o repositório.

#### Decisões técnicas
- Fundo neutro em gradiente em vez de fotografia: menos espetacular parado, mas coerente em movimento — o realismo percebido depende mais da consistência do que da resolução do fundo.
- O environment map fica desacoplado do fundo visível: os reflexos continuam fotográficos com o céu em gradiente.

#### Problemas / limitações
- O wash continua a ser uma aproximação por sprites; sem simulação de fluido, a espuma não interage com a ondulação da água.
- O site nunca foi renderizado num telemóvel real — media queries e LOWQ estão validados apenas por inspeção de código.

#### Resultado do dia
- Palco visualmente estável: jatos com aspeto de wash real, fundo que não compete com o movimento da câmara, repositório pronto para commit, push e ativação do GitHub Pages.

#### Lições aprendidas
- Fotografia de fundo fixa é incompatível com câmara livre; ou o fundo é 360º (panorâmica esférica) ou é neutro. Meio-termo não existe.
- Vale a pena separar o papel visual de um asset (fundo) do papel de iluminação (envmap) — remover um não obriga a perder o outro.

#### Próximo passo
- `git add -A && git commit && git push`; ativar Pages (Settings → Pages → Source: GitHub Actions) e verificar o site publicado, sobretudo no telemóvel.

### 2026-07-28

(Sessão da noite de 28 para 29; os commits correspondentes ficam com data de 29.)

#### Trabalho realizado
- Fechada a arquitetura do kill-switch remoto, que estava em aberto desde a v1.10 (OPEN-008). Corte por relé na linha positiva de cada casco, a jusante do fusível e da loop key, comandado por um canal PWM de rádio que não atravessa o Raspberry Pi nem o ESP32.
- Verificado no modelo v6_4 que a abertura de acesso às baterias sobreviveu às revisões v6_3/v6_4 (0 cm³ de material na janela do convés nos dois cascos) e que nada obstrui a extração vertical além da própria escotilha.
- Medido em simulação o desequilíbrio de trabalho entre cascos em quatro missões: 0,0 % em linha reta, −1,6 % em ziguezague, +8,9 % na missão de demonstração e +13,6 % num quadrado com viragens todas do mesmo lado.
- Calculada a autonomia comparada das baterias em função do tempo a andar, e reatribuídos os quatro canais do ADS1015.
- Confirmada fisicamente a bateria da eletrónica como LiPo 3S 2200 mAh.
- Corrigidos os três sítios do site publicado que indicavam 2S 2200 (`website/assets/js/data.js` ×2 e `i18n.js`).
- Produzido `docs/SAILSAFE_Architecture_v1_12.docx` (nova secção 21, histórico e tabelas de decisões e BOM actualizados) e revista a especificação `hardware/electrical/SAILSAFE_sense_v1_11_1.md` para a revisão 2.
- Levantada e orçamentada a lista de compras; escolhido o caminho de menor custo para o rádio.

#### Decisões técnicas
- O corte remoto atua no POSITIVO, nunca no negativo. O negativo de cada casco é a referência de massa e o seu único caminho até à massa da eletrónica é o fio preto da ficha servo do ESC; cortá-lo obrigaria a corrente de retorno a passar por um fio dimensionado para miliamperes.
- Hierarquia de proteção fixada em fusível (40–50 A) < relé (60–70 A) < cabo (6 mm²). O fusível tem de ser o elo mais fraco por ser o único componente desenhado para falhar de forma controlada. Descartada a hipótese de dimensionar o fusível também a 60–70 A por simetria com o relé: nesse caso deixaria de proteger o ESC de 40 A, que arderia sem o fusível chegar a atuar.
- Bobinas dos relés alimentadas pela bateria do próprio casco, a montante dos contactos: alimentá-las pela bateria da eletrónica custaria ~35 % da autonomia desta (1,9 h → 1,3 h), contra 4–6 % por missão quando saem do casco.
- Um módulo RC-switch por casco, não um partilhado: um só módulo obrigaria a corrente das bobinas a atravessar a ponte pela massa da eletrónica e criaria um ponto único de falha a comandar os dois cascos. Um único canal do recetor comanda ambos.
- O caminho do kill não passa por software do projeto. O PWM do ESP32 é gerado pelo periférico LEDC, em hardware: se o firmware encravar sem reiniciar, o sinal mantém-se com o último valor e o failsafe de software nunca chega a correr.
- Loop keys XT90-S mantidas e não substituídas pelo corte remoto. Respondem a perguntas diferentes: a chave garante que é seguro pôr as mãos junto aos jatos, o rádio garante que o barco pára à distância. Descartada a ideia de as accionar por cordel — o XT90 tem vários quilos de retenção e não é um cordão de emergência; a extração das baterias faz-se pela escotilha.
- Corte apenas de um polo: cortar um já isola a bateria por completo, e cortar o segundo acrescentaria um contacto a mais para arcar ou corroer sem ganho de segurança.
- Sense reatribuído a três tensões (dois cascos e eletrónica) e uma corrente. Um divisor custa cêntimos e um sensor de corrente custa euros, logo o recurso escasso é o canal e não o componente.
- Divisores passam a 5k/1k, aproveitando resistores já disponíveis. Condensador de filtro sobe para 2,2 µF porque a impedância de fonte desceu de 1,80 kΩ para 833 Ω.
- A bateria da eletrónica passa a gatilho de regresso, e não apenas a mostrador.

#### Problemas / limitações
- Com 5k/1k, o limite de saturação no FSR por omissão sobe para 12,29 V — ainda abaixo de uma 3S carregada. A troca de divisor não dispensa a configuração do PGA para ±4,096 V.
- **Revertida a decisão de 07-26.** Nessa sessão a divergência sobre a bateria da eletrónica foi fechada a favor do esquema elétrico (2S 2200), por ser o documento mais recente. Estava errado: a bateria física é 3S 2200, e as secções 5.2 e 17.6 do documento de arquitetura, mais antigas, é que estavam certas. Critério corrigido para o futuro: perante documentos em conflito sobre uma peça física, verifica-se a peça e não a data do documento.
- O esquema elétrico v1.11 indica 2S 2200 mAh para a eletrónica quando a bateria real é 3S 2200 mAh. As secções 5.2 e 17.6 do documento de arquitetura já indicavam 3S, portanto o erro está no esquema. Correção pendente no KiCad.
- Continua sem sobrar canal para monitorizar o rail de 5 V, do qual a saída do ACS758 é ratiométrica.
- O casco direito fica sem medição de corrente até haver segundo ADS1015.
- Um jato obstruído no casco não instrumentado não é detetado diretamente; só indiretamente pela queda de tensão.
- Orçamento por fechar. Apenas o recetor ELRS ER6 tem preço confirmado (29,90 €, distribuidor europeu); as restantes rubricas assentam em ordens de grandeza e carecem de cotação antes de encomendar.
- Nada disto está verificado em hardware: continuam em falta ESCs, motores, GPS, relés e rádio.

#### Resultado do dia
- A última decisão estrutural em aberto desde a v1.10 ficou fechada, e com ela o caminho para ensaios na água sem corda deixa de estar bloqueado por indefinição de arquitetura — passa a estar bloqueado apenas por compras.
- Identificada uma inversão de prioridades que estava errada desde o início: a bateria pequena, e não as de propulsão, é o recurso crítico do sistema.

#### Lições aprendidas
- Duas baterias não se comparam pela capacidade mas pelo relógio a que se gastam. Uma consome-se com o tempo, a outra com a distância, e por isso a mais pequena pode ser a que limita a missão.
- Em cadeias de proteção, cada componente é dimensionado por um critério diferente e em sentidos opostos: o fusível pelo mínimo que protege, o relé e o cabo pelo máximo que suportam. Aplicar o mesmo número a todos anula a proteção.
- Segurança encaminhada através de um sistema que pode falhar não é segurança. O corte de emergência tem de ser independente daquilo de que desconfia.
- Peças que parecem alternativas podem responder a perguntas diferentes. A loop key e o corte remoto não competem: uma protege as mãos, a outra protege o barco à distância.
- Documentos que se contradizem entre si custam mais a descobrir do que um erro isolado. Convém confrontar o esquema com o documento-mãe sempre que se toca num valor.

#### Próximo passo
- Confirmar na ficha do ESC escolhido o comportamento ao perder sinal (OPEN-010), porque determina se um corte ao nível do sinal seria sequer admissível.
- Decidir o sistema de rádio (OPEN-011) e encomendar.
- Corrigir o esquema elétrico no KiCad: 3S 2200 mAh, três divisores 5k/1k, condensadores de 2,2 µF, nota do PGA junto de U4.
- Interface `RealHeading` para o BNO055, ainda por fazer.
- Buffer circular de logging como exercício de AED.
- Modo manual com comando de consola ligado ao Raspberry Pi, como forma de exercitar o código e pilotar em ensaios próximos sem depender do rádio.

### 2026-07-29

#### Trabalho realizado
- Escrito `control/real_heading.py`: leitor de rumo real do BNO055 com a mesma interface `read()` do `SimulatedHeading`, mais o tratamento de tudo o que a fonte simulada nunca teve de tratar (calibração NDOF, ausência de solução de fusão, I2C em baixo, offset de montagem, declinação magnética).
- Escrito `tools/heading_bench.py`: ensaio de "rodar à mão". Não abre a série nem fala com o ESP32; calcula e imprime os L/R que o mixer daria, sem os enviar. Tem modo `--fake` para exercitar o ecrã sem hardware.
- Escritos 13 testes em `tests/test_real_heading.py`, todos com driver falso e sem hardware. Os 18 testes anteriores continuam a passar.
- Arquivadas 10 versões antigas de CAD em `hardware/mechanical/archive/`, com README a explicar o que está lá e o que deliberadamente não está.
- Corrigido `tools/README.md`, que ainda dava o v6_3 como modelo corrente e não listava o `build_concept_v6_4.py`.
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

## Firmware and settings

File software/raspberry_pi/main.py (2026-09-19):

#!/usr/bin/env python3
"""SAILSAFE - processo principal do Raspberry Pi.

Maquina de estados: DISARMED <-> ARMED / NAV.
- Arranca sempre em DISARMED (seguro).
- DISARMED: nunca envia propulsao; motores parados pelo failsafe do ESP32.
- ARMED: envia heartbeat a 5 Hz (0/0) para manter o failsafe satisfeito.
- NAV: navegacao por waypoints. O WaypointNav da o bearing para o waypoint
  atual, que passa a ser o alvo do heading hold (ja nao um rumo fixo). O
  controlador calcula o steer, o mixer converte em L/R (<=30%) e o comando
  segue para o ESP32, fechando a malha pelo barco SINTETICO (sem GPS, BNO055
  nem motores). Trocar as fontes pelas reais nao altera a logica de controlo.
- Fim de missao: para os motores e volta a DISARMED (estado seguro).
- STOP tem prioridade absoluta e forca DISARMED.
- O regresso da ligacao serie nunca arma sozinho.
- Fontes sinteticas NUNCA comandam motores sem ser pedido na linha de
  comandos. Ver nav_guard() e os modos --sim / --sim-motores.
- Com --gps a posicao vem do NEO-8M e e registada em todos os estados,
  nao so em NAV: uma sessao de bancada passa a deixar dados de dispersao
  sem ser preciso correr o tools/gps_bench.py ao lado.
- Perder posicao em NAV leva a estado seguro, com a mesma politica da
  perda de serie e uma tolerancia curta. Ver PositionWatch.
- O ponto de regresso e gravado no ARM, a partir de fixes validados, e
  nao se reescreve. Sem ele, com --gps, o ARM e recusado.
- O STOP e repetido ate o ESP32 confirmar; nao confirmar e ruidoso e fica
  no log. Ver communication/serial_link.py.
- ARMAR exige confirmacao de que a trava do ESP32 abriu. Sem prova de que
  a propulsao esta destravada, o sistema fica DISARMED.
- O controlo nao depende de terminal: FIFO e SIGUSR1 funcionam debaixo de
  systemd ou nohup. Ver commands.py.

Regista a sessao em CSV via telemetry.SessionLogger.
Comandos: a=ARM  n=NAV  d=DISARM  s=STOP  q=sair
  terminal (se houver tty)  |  echo s > FIFO  |  kill -USR1 <pid> (STOP)
"""

import argparse
import math
import os
import signal
import time
from collections import namedtuple

from commands import CommandBus, DEFAULT_FIFO
from communication.serial_link import SerialLink
from telemetry.logger import SessionLogger
from control.heading import HeadingController
from control.mixer import mix
from control.navigation import WaypointNav
from control.real_position import PositionUnavailable, RealBoat, create_neo8m
from control.return_point import ReturnPoint, ReturnPointUnavailable
from control.sources import SimulatedBoat, SimulatedHeading

HEARTBEAT_S = 0.2
RECONNECT_S = 10
SAFE_MAX = 30        # teto que o ESP32 aceita (rejeita comandos > 30%)
NAV_THROTTLE = 20    # impulso base em NAV, com margem para o steer
ARRIVAL_RADIUS_M = 4.0
DISARMED, ARMED, NAV = "DISARMED", "ARMED", "NAV"

GPS_PORT = "/dev/serial0"
GPS_POLL_S = 0.5     # o modulo emite a 1 Hz; ler ao dobro nao deixa acumular
GPS_LOG_S = 1.0      # uma linha de posicao por segundo no CSV da sessao
GPS_PRINT_S = 5.0    # no ecra e so para o operador ver que ha sinal

# Ciclos de NAV seguidos sem posicao antes de abortar a missao. Ver
# PositionWatch para o porque de nao ser 1.
NAV_POS_MISSES = 3

# Missao SINTETICA de demonstracao: 40 m a Norte, depois mais 40 m a Este.
# As coordenadas sao DERIVADAS de uma origem, e nao escritas a mao, para
# que a mesma missao possa ser montada a partir do ponto de regresso real
# quando ha GPS. Waypoints absolutos so tinham sentido enquanto a origem
# tambem era inventada.
MISSION_START = (38.73600, -9.14000)
MISSION_OFFSETS_M = [
    (40.0, 0.0),     # ~40 m a Norte  (bearing 0)
    (40.0, 40.0),    # e mais ~40 m a Este  (bearing 90 no segundo troco)
]

METRES_PER_DEG_LAT = 111320.0


def mission_from(lat, lon, offsets=MISSION_OFFSETS_M):
    """Waypoints a partir de uma origem, com deslocamentos em metros.

    offsets sao pares (norte, este) em metros. A conversao usa a latitude
    da origem para todos os pontos: a esta escala (dezenas de metros) a
    diferenca e de centimetros, muito abaixo da dispersao do proprio GPS.
    Nao serve para missoes de quilometros, e nao e para isso que existe.
    """
    escala_lon = METRES_PER_DEG_LAT * math.cos(math.radians(lat))
    return [(lat + norte / METRES_PER_DEG_LAT, lon + este / escala_lon)
            for norte, este in offsets]


MISSION_WAYPOINTS = mission_from(*MISSION_START)

running = True


def shutdown(signum, frame):
    global running
    print(f"\n[INFO] Sinal {signum} recebido. A terminar em seguranca.", flush=True)
    running = False


def motivo_sem_fix(gps):
    """Porque e que nao ha posicao agora, em linguagem util.

    O last_reject do RealPosition diz porque e que a ultima trama foi
    RECUSADA por criterio -- satelites, HDOP, ilha nula. Nao cobre o caso
    em que houve fixes bons e o modulo se calou: aí nada foi recusado, e o
    last_reject fica preso no "ainda sem leituras" do arranque, que e
    exatamente a mensagem errada. Silencio e recusa sao defeitos com
    remedios opostos, e o ecra tem de os distinguir.
    """
    idade = gps.fix_age()
    if idade is not None and idade > gps.max_stale_s:
        return (f"ultimo fix ha {idade:.1f} s (maximo "
                f"{gps.max_stale_s:.1f} s) -- modulo calado")
    return gps.last_reject


def qualidade(valor, fmt=".2f"):
    """Formata satelites/HDOP, que podem nao existir.

    As tramas RMC dao posicao e nao dao qualidade nenhuma: satellites e
    hdop vem a None e o Fix e aceite na mesma, porque o estado 'A' ja diz
    que ha fix. Quem regista isto tem de saber a diferenca entre "nao
    medido" e "zero" -- formatar None como se fosse numero rebenta, e
    imprimir 0 seria pior, porque parecia uma medicao.
    """
    return "n/d" if valor is None else format(valor, fmt)


NavStep = namedtuple("NavStep", "left right bearing dist done lat lon")


def stop_confirmado(link, log, state, motivo):
    """Manda parar, regista o resultado e diz alto se nao foi confirmado.

    Devolve o StopResult. Um StopResult so e verdadeiro quando confirmado,
    portanto `if stop_confirmado(...)` ja e a leitura conservadora.

    Nao confirmar nao e "os motores continuam a andar": e "nao sabemos se
    o comando chegou, e o failsafe do ESP32 trava a propulsao dentro de
    1 s". A diferenca entre as duas leituras passa a estar no log em vez
    de ficar por adivinhar.

    Sem porta aberta nao ha alarme nenhum. Um STOP sem serie nao falhou:
    nunca houve caminho para a propulsao, portanto nao ha nada a parar.
    Gritar aqui seria gritar em todas as sessoes de simulacao sem ESP32 --
    e um alarme que dispara quando nao esta nada em jogo e um alarme que
    se aprende a ignorar, o que o torna pior do que nao existir.
    """
    havia_porta = link.is_open
    r = link.stop_motors()
    for linha in r.lines:
        print(f"[RX] {linha}", flush=True)
        log.log("RX", state, linha)
    if r.confirmed:
        log.log("STOP", state, f"{motivo}: confirmado ({r.attempts} tent.)")
    elif not havia_porta:
        log.log("STOP", state, f"{motivo}: sem serie, nada para parar")
    else:
        log.log("ALERTA", state, f"{motivo}: STOP NAO confirmado - {r.reason}")
        print(f"[ALERTA] STOP nao confirmado pelo ESP32 ({r.reason}).", flush=True)
        print("[ALERTA] O failsafe trava a propulsao ~1 s apos o ultimo "
              "comando. Cortar a alimentacao se houver duvida.", flush=True)
    return r

# --- guarda do modo NAV -------------------------------------------------
# O nav_step() fecha a malha no SimulatedBoat: le a posicao dele, calcula
# L/R a partir dela e realimenta-o. Se esses mesmos L/R seguirem para o
# ESP32, motores reais executam a missao de um barco que so existe em
# memoria -- o barco fisico vai onde calhar e o sintetico "chega" ao
# waypoint. A malha fica fechada no lado errado.
#
# Por isso o modo NAV pergunta pela PROVENIENCIA das fontes antes de deixar
# comandar seja o que for.

NAV_RECUSADO = "recusado"      # fontes sinteticas sem autorizacao explicita
NAV_SEM_MOTORES = "sem_motores"  # simulacao: calcula e imprime, envia so 0/0
NAV_COM_MOTORES = "com_motores"  # propulsao real segue para o ESP32


def is_synthetic(source):
    """True se a fonte for sintetica.

    O valor por omissao e True de proposito: uma fonte que nao se declara
    e tratada como sintetica e o NAV recusa. Falhar para o lado conservador
    e a mesma politica do RealHeading -- perante duvida, nao dar numero.
    """
    return getattr(source, "SYNTHETIC", True)


def nav_guard(sources, allow_sim=False, sim_drives_motors=False):
    """Decide se o NAV pode arrancar e se pode comandar motores.

    Devolve (modo, motivo). O modo e uma das constantes NAV_* acima.

    Regra: com fontes reais, o NAV comanda os motores -- e para isso que
    existe. Com fontes sinteticas exige-se um pedido explicito na linha de
    comandos, e mesmo assim a propulsao so sai com --sim-motores. O
    --sim sozinho segue o padrao ja usado no tools/heading_bench.py:
    calcula os comandos e imprime-os sem os enviar.
    """
    sinteticas = [s for s in sources if is_synthetic(s)]
    if not sinteticas:
        return NAV_COM_MOTORES, "fontes reais"
    nomes = ", ".join(type(s).__name__ for s in sinteticas)
    if sim_drives_motors:
        return NAV_COM_MOTORES, f"--sim-motores com fontes sinteticas ({nomes})"
    if allow_sim:
        return NAV_SEM_MOTORES, f"--sim: fontes sinteticas ({nomes}), sem propulsao"
    return NAV_RECUSADO, (f"fontes sinteticas ({nomes}) sem --sim. "
                          "Motores reais nao seguem um barco imaginario.")


# --- perda de posicao em NAV --------------------------------------------
# O RealPosition ja se recusa a devolver uma posicao velha: passados
# max_stale_s levanta PositionUnavailable em vez de entregar a ultima
# conhecida. Falta decidir o que o barco faz com essa recusa, e e isso que
# esta classe decide.
#
# Porque nao abortar a primeira falha: a 1 Hz, uma unica trama perdida
# poe a idade do fix no limite. Um aborto por cada mensagem perdida seria
# um alarme a disparar quando nao se passa nada -- e o projeto ja escreveu,
# a proposito dos contadores do gps_bench, que um alarme desses e pior do
# que nao existir, porque se aprende a ignora-lo.
#
# Porque nao seguir em frente: navegar sem posicao e navegar as cegas, e a
# unica coisa que o barco sabe fazer as cegas e continuar a andar para onde
# estava virado. Durante a tolerancia a propulsao vai a ZERO e o heartbeat
# continua -- o barco fica parado e comandavel, em vez de parado pelo
# failsafe ou a andar sem saber para onde.
#
# O orcamento total de silencio e max_stale_s + max_misses * HEARTBEAT_S,
# hoje 2,5 + 3 x 0,2 = 3,1 s.

class PositionWatch:
    """Conta falhas seguidas de posicao e decide quando abortar a missao.

    LATCHING, pela mesma razao da guarda de bateria e da trava do ESP32:
    recuperar o fix nao desfaz o aborto. Um GPS que volta a si sozinho
    reiniciaria a missao a meio, sem ninguem ter decidido nada -- e um
    caminho de "parado por falha" para "a andar" sem gesto humano pelo
    meio e exatamente o que o resto do sistema recusa ter.

    Nao faz I/O: quem chama e que apanha a excecao e reporta o resultado.
    """

    def __init__(self, max_misses=NAV_POS_MISSES):
        self.max_misses = max_misses
        self.misses = 0
        self.tripped = False
        self.reason = ""

    def ok(self):
        """Posicao valida: limpa a contagem. Nao levanta um aborto ja dado."""
        self.misses = 0
        return self.tripped

    def miss(self, motivo):
        """Falha de posicao. Devolve True quando a missao tem de abortar."""
        self.misses += 1
        if self.misses >= self.max_misses:
            if not self.tripped:
                self.reason = f"{self.misses} ciclos sem posicao: {motivo}"
            self.tripped = True
        return self.tripped

    def reset(self):
        """Limpa o aborto. Gesto explicito -- entrar em NAV ou em ARM."""
        self.misses = 0
        self.tripped = False
        self.reason = ""

    def describe(self):
        if self.tripped:
            return f"abortado ({self.reason})"
        if self.misses:
            return f"{self.misses}/{self.max_misses} ciclos sem posicao"
        return "posicao valida"


def nav_step(nav, ctrl, boat, throttle=NAV_THROTTLE, cap=SAFE_MAX, dt=HEARTBEAT_S):
    """Um passo de navegacao autonoma, sem qualquer I/O.

    Le a posicao do barco, pede ao WaypointNav o bearing para o waypoint
    atual e usa-o como alvo do heading hold; o controlador da o steer, o
    mixer converte em comandos de motor limitados a [0, cap], e o resultado
    realimenta o barco SINTETICO (fecha a malha).

    Devolve um NavStep. Com a missao concluida devolve left=right=0 e
    done=True, ou seja, sem propulsao.

    Nao toca em serie nem em ficheiros, para poder ser testado sem hardware.
    """
    lat, lon = boat.position()
    bearing, dist, done = nav.update(lat, lon)
    if done:
        return NavStep(0, 0, None, 0.0, True, lat, lon)
    ctrl.set_target(bearing)                     # o alvo passa a vir do waypoint
    steer = ctrl.update(boat.heading)            # rumo medido antes de atuar
    left, right = mix(throttle, steer, 0, cap)
    boat.update(left, right, dt=dt)              # SINTETICO: fecha a malha
    return NavStep(left, right, bearing, dist, False, lat, lon)


def parse_args(argv=None):
    p = argparse.ArgumentParser(description="SAILSAFE - processo principal.")
    p.add_argument("--sim", action="store_true",
                   help="permite NAV com fontes sinteticas; calcula e imprime "
                        "os comandos SEM os enviar (so heartbeat 0/0)")
    p.add_argument("--sim-motores", action="store_true", dest="sim_motores",
                   help="PERIGO: NAV com fontes sinteticas a comandar mesmo os "
                        "motores. So com o barco preso na bancada.")
    p.add_argument("--esp32-port", default=None, dest="esp32_port",
                   help="porta serie do ESP32. Por omissao a do SerialLink "
                        "(/dev/ttyUSB0). Um nome estavel de "
                        "/dev/serial/by-id/ evita que dois dispositivos USB "
                        "troquem de numero entre arranques.")
    p.add_argument("--gps", action="store_true",
                   help="usa o GPS real (NEO-8M) como fonte de posicao. Sem "
                        "isto a posicao e a do barco sintetico.")
    p.add_argument("--gps-port", default=GPS_PORT, dest="gps_port",
                   help=f"porta serie do GPS (por omissao {GPS_PORT})")
    p.add_argument("--control-fifo", default=DEFAULT_FIFO, dest="control_fifo",
                   help=f"FIFO de comandos (por omissao {DEFAULT_FIFO}). "
                        "Vazio desliga o FIFO.")
    p.add_argument("--no-tty", action="store_true", dest="no_tty",
                   help="ignora o teclado mesmo havendo terminal")
    return p.parse_args(argv)
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

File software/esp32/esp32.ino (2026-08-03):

// SAILSAFE - controlo dos ESCs no ESP32.
//
// Este ficheiro trata do HARDWARE: serie, pinos, sinal PWM. Toda a decisao
// de seguranca (tecto de 30%, failsafe por timeout, trava de re-arme) esta
// em motor_safety.h, que nao depende do Arduino e e testado com g++ em
// software/esp32/tests/.
//
// Protocolo: "L: <0-30> R: <0-30>\n"
// O sistema arranca TRAVADO. Ate receber "L: 0 R: 0" nao ha propulsao.
//
// -------------------------------------------------------------------------
// PORQUE E QUE ISTO SE CHAMA esp32.ino
//
// O Arduino exige que o sketch principal tenha exatamente o mesmo nome da
// pasta que o contem. Como a pasta e software/esp32/, o ficheiro tem de ser
// esp32.ino. Chamou-se esp32_boat_.ino ate 2026-08-04, e com esse nome o
// `arduino-cli compile` nao encontrava o sketch ("main file missing from
// sketch") -- ou seja, o firmware que segura os ESCs nao era compilavel pela
// linha de comandos, so aberto a mao no IDE.
//
// As pastas tests/ e tools/ ficam onde estao: o builder do Arduino so
// compila os ficheiros na raiz do sketch e o que estiver dentro de src/,
// portanto ignora-as. E o que permite ter os cabecalhos falsos do
// syntax_check.sh em tools/stub/ sem que eles tapem os verdadeiros.
// -------------------------------------------------------------------------

#include <ESP32Servo.h>
#include "motor_safety.h"

using namespace sailsafe;

Servo escLeft;
Servo escRight;

const int LEFT_ESC_PIN = 18;
const int RIGHT_ESC_PIN = 19;

MotorSafety safety;

static char serialBuffer[64];
static int bufferIndex = 0;
static bool avisoTravaImpresso = false;

void setup() {
  Serial.begin(115200);
  delay(1000);

  escLeft.setPeriodHertz(50);
  escRight.setPeriodHertz(50);

  escLeft.attach(LEFT_ESC_PIN, PWM_STOP, PWM_MAX);
  escRight.attach(RIGHT_ESC_PIN, PWM_STOP, PWM_MAX);

  safety.begin(millis());
  aplicarPWM();

  Serial.println("ESP32 motor controller iniciado");
  Serial.println("Formato: L: 10 R: 10   (terminar com \\n)");
  Serial.println("Limite seguro atual: 0% a 30%");
  Serial.println("PROPULSAO TRAVADA no arranque - enviar 'L: 0 R: 0' para destravar");
}

void loop() {
  readSerialNonBlocking();

  if (safety.tick(millis())) {
    Serial.println("FAILSAFE ATIVO - motores parados e propulsao TRAVADA");
    Serial.println("Enviar 'L: 0 R: 0' para destravar");
    avisoTravaImpresso = false;
  }

  aplicarPWM();

  delay(20);
}

void aplicarPWM() {
  escLeft.writeMicroseconds(safety.leftPWM);
  escRight.writeMicroseconds(safety.rightPWM);
}

void readSerialNonBlocking() {
  while (Serial.available()) {
    char c = Serial.read();

    if (c == '\n') {
      serialBuffer[bufferIndex] = '\0';
      processCommand(serialBuffer);
      bufferIndex = 0;
    } else {
      if (bufferIndex < 63) {
        serialBuffer[bufferIndex++] = c;
      }
    }
  }
}

void processCommand(char *cmd) {
  CmdResult r = safety.handleLine(cmd, millis());

  switch (r) {
    case CMD_MALFORMED:
      Serial.println("COMANDO INVALIDO - motores parados");
      break;

    case CMD_OUT_OF_RANGE:
      Serial.println("VALOR FORA DO LIMITE SEGURO - motores parados");
      break;

    case CMD_LOCKED:
      // Nao inunda a consola: o Pi manda comandos a 5 Hz.
      if (!avisoTravaImpresso) {
        Serial.println("PROPULSAO TRAVADA - ignorado. Enviar 'L: 0 R: 0' para destravar");
        avisoTravaImpresso = true;
      }
      break;

    case CMD_IDLE:
      Serial.println("Parado. Propulsao DESTRAVADA");
      avisoTravaImpresso = false;
      break;

    case CMD_OK:
      Serial.print("Left: ");
      Serial.print(safety.leftPWM);
      Serial.print(" us | Right: ");
      Serial.print(safety.rightPWM);
      Serial.println(" us");
      break;
  }
}

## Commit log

2026-07-07 Update README with project overview
    Expanded project description and added sections for overview, current status, main components, repository structure, focus, and author.
2026-07-07 Add engineering log for SAILSAFE project
    Documentação do diário de engenharia do projeto SAILSAFE, incluindo progresso, problemas e próximos passos.
2026-07-07 Enhance README with project details and structure
    Added current phase, control focus, and documentation sections to README.
2026-07-14 Update engineering log with power supply details
    Consolidated the 5V power supply chain for Raspberry Pi 4 and defined procedures for GPIO pin identification and soldering. Documented technical decisions, problems, and next steps.
2026-07-16 Update Engineering log with July 15, 2026 activities
    Documented the validation and testing of Raspberry Pi power supply and systemd configuration. Included technical decisions, identified risks, and next steps for further development.
2026-07-17 Update Engineering log with recent project developments
    Documented work completed on development strategy and technical decisions, including adjustments due to logistical constraints and budget limitations. Outlined next steps and identified risks associa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
2026-07-19 Update Engineering log with architecture revisions and findings
    Documented the work done on the mechanical and electrical architecture, including weight distribution studies, circuit design, and safety protocols. Updated the architecture document to version 1.11 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
2026-07-20 Refactor serial_link: script de teste -> classe SerialLink reutilizavel
    - Nenhuma acao ao importar; sem valores fixos aos motores (so STOP 0/0)
    - connect() devolve True/False em vez de crashar sem ESP32
    - Protocolo L:/R: intacto
    [serial_link.py]
2026-07-20 Integra SerialLink no main.py e move-o para raspberry_pi/
    - main.py passa a abrir/escutar a ligacao serie, com religacao a cada 10 s
    - Continua DISARMED: nunca envia comandos de propulsao
    - STOP + fecho da porta garantidos ao sair (SIGINT/SIGTERM)
2026-07-20 Refactor serial_link.py and integrate with main.py
    Refactor `serial_link.py` to a reusable class and integrate with `main.py`. Validate communication with ESP32 and ensure failsafe functionality.
2026-07-21 main.py: maquina de estados DISARMED/ARMED com heartbeat
    - ARMED envia heartbeat 5 Hz (0/0) que mantem vivo o failsafe do ESP32
    - DISARMED nunca envia propulsao; arranca sempre em DISARMED
    - STOP tem prioridade absoluta e forca DISARMED
    - Perda de ligacao ou regresso da mesma nunca arma sozinho
    - Controlo por teclado (a/d/s/q) para teste em bancada
    [main.py]
2026-07-21 main.py: integra SessionLogger na maquina de estados
    - Regista BOOT, SERIAL, STATE, TX, RX, STOP, WARN e SHUTDOWN em CSV
    - Uma linha por evento com timestamp ao milissegundo
    - Permite reconstruir cada sessao para analise posterior
2026-07-22 serial_link: buffer de linhas completas + flush no arranque
2026-07-22 control: heading hold proporcional + normalizacao de erro angular
2026-07-22 control: mixer throttle/steer->L/R + fonte de heading simulada
2026-07-23 control: navegacao por waypoints (haversine, bearing, WaypointNav) + SimulatedBoat
2026-07-23 Arquitetura v1.11 + blueprint v6.1 + STEP de conceito; log completo; README atualizado; renomeia hardware/electrical
    [SAILSAFE_concept_v6_1.step]
2026-07-24 STEP conceito v6.2: aberturas de acesso as baterias nos cascos; log 07-24
    [SAILSAFE_concept_v6_2.step]
2026-07-26 NAV segue waypoints (bearing do WaypointNav) + testes; sense v1.11.1
2026-07-27 STEP conceito v6.4: componentes detalhados e waterjets vetorizados
    [SAILSAFE_concept_v6_4.step]
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2026-07-27 Site interativo (viagem 3D + viewer), STEP v6.4 com componentes detalhados, log 07-26/27
    [SAILSAFE_concept_v6_3.step, SAILSAFE_concept_v6_3.stl]
2026-07-28 Arquitetura v1.12: kill-switch remoto fechado (OPEN-008), bateria da eletronica 3S 2200, sense rev2
2026-07-29 RealHeading para o BNO055 + ensaio de bancada sem motores
    Leitor de rumo real com a mesma interface read() do SimulatedHeading.
    Trata o que a fonte simulada nunca teve de tratar: calibracao NDOF
    insuficiente, euler sem solucao, I2C em baixo, offset de montagem e
    declinacao magnetica. Perante duvida nao devolve numero: levanta
    HeadingUnavailable e deixa o estado seguro ao chamador.
    Tolerancia de max_stale_s (0,5 s por omissao) para que uma leitura
    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
2026-07-30 Arquiva CAD antigo, corrige docs do build e log de 07-29
    Move 10 versoes antigas para hardware/mechanical/archive/ com README.
    NAO arquivados, apesar de parecerem versoes velhas:
    - v6_2 e o SRC por omissao de build_concept_v6_3/v6_4; arquiva-la
    partia a reconstrucao do modelo corrente.
    - v6_3 e a geometria de que foi feito o sailsafe.glb publicado.
    - hull.step e o casco base do Fusion.
    tools/README.md dava o v6_3 como corrente e nao listava o
    build_concept_v6_4.py. Corrigido.
    Log de 07-29 registando o RealHeading, o arquivo, a ordem de trabalhos
    do hardware, e uma pendencia nova: o verify_concept.py rebenta no v6_4
    (KeyError raspberry_pi_4) porque o v6_4 decompos os modulos em
    sub-pecas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
    [SAILSAFE_concept_v1.step, SAILSAFE_concept_v2.step, SAILSAFE_concept_v2_advbrep.step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]
2026-07-30 verify_concept: analise por modulo + verificacao de integridade; folgas e CG voltam a correr no v6_4
2026-07-30 NAV: guarda de proveniencia das fontes (--sim / --sim-motores); revisao da cadeia de seguranca
2026-07-30 esp32: failsafe trava a propulsao (so abre com L: 0 R: 0); logica separada em motor_safety.h com 13 testes em g++
    [esp32_boat_.ino, main.py, test_motor_safety.cpp]
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2026-08-03 palco: corrigir desempenho, enquadramento e contraste
    Desempenho:
    - agua: iterar so os vertices dentro do disco da ondulacao e obter a
    normal da derivada analitica em vez de computeVertexNormals(), que
    percorria os 24 200 triangulos do plano a cada frame (18x menos CPU)
    - pausar os dois renderers WebGL quando saem do ecra ou o separador
    fica escondido; marcadores passam a correr no loop da viagem
    - passo de tempo real em vez de 0,016 s fixo
    - material da agua sem clearcoat e malha mais leve em ecras de toque
    - remover as duas panoramicas em esferas invisiveis (4,26 MB que eram
    transferidos e enviados para a GPU sem nunca aparecer no ecra)
    Enquadramento:
    - barco sempre ao centro; o e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
2026-08-03 seguranca: STOP confirmado pelo ESP32 e controlo sem terminal
    Fecha os dois defeitos que restavam da revisao da cadeia de seguranca de
    07-30. Sessao sem hardware: ambos sao de politica e testam-se num PC.
    STOP confirmado:
    - stop_motors() repete ate o ESP32 confirmar e devolve StopResult com o
    que foi enviado, o que foi confirmado e as linhas lidas pelo caminho. A
    confirmacao ja existia no protocolo sem estar a ser usada: "L: 0 R: 0" e
    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
2026-09-14 Sense do ADS1015, leitor de GPS e guarda de bateria; arquitetura v1.13, procedimento de sensores e correcoes do site
2026-09-15 Contadores do gps_bench separados: checksum mau, sem fix, recusadas, aceites
    [real_position.py]
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2026-09-19 GPS integrado no processo: --gps, perda de posicao para estado seguro e ponto de regresso
    - --gps no main.py: posicao lida e registada em TODOS os estados, nao so
    em NAV. Se a porta nao abrir o processo sai, em vez de continuar com o
    barco sintetico a fazer de posicao sem ninguem dar por isso.
    - PositionWatch: tres ciclos seguidos sem posicao abortam a missao com
    STOP confirmado e DISARMED. Durante a tolerancia a propulsao vai a zero
    e o heartbeat continua. Latching, como a trava do ESP32.
    - control/return_point.py: ponto de regresso por media de fixes validados
    numa janela deslizante, gravado no ARM e nunca reescrito. Com --gps, o
    ARM e recusado sem ele. Verificado antes da trav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
    [main.py, real_position.py, return_point.py]
2026-09-20 log: fundo dos alojamentos sobe para z=80; massa por pesar (OPEN-015, OPEN-016)
2026-09-25 Pesagem dos componentes, teto de 30% por fase, fusivel de bancada, proximos passos
    Claude-Session: https://claude.ai/code/session_01AUkmk73whxzv1PP3pPC2gY
2026-09-25 Pesagem dos componentes, proximos passos e nota de autoria: logs e commits com IA
2026-09-25 Pesagem, proximos passos, nota de autoria; fusivel de bancada fica nos 30 A
2026-11-10 BNO055 novo: primeiro rumo real; quarentena de saltos e calibracao gravada
    Placa da Devantech com o link de I2C fechado, 0x28 e 0x48 estaveis,
    calibracao 3333 a mao e rumo estavel. Quedas do barramento atribuidas
    aos jumpers (zero falhas com femea-femea).
    RealHeading: leitura que implique rodar acima de max_rate_dps desde a
    ultima boa fica de quarentena, aceite so se a seguinte a confirmar
    (caso real 23 -> 134 -> 25 a 5 Hz). save/load_calibration dos offsets,
    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
2026-11-10 BNO055: calibracao carregada valida no Pi; gate nao protege contra offsets errados
    Ensaio real: --carregar-cal deu 3333 em ~1 s sem movimento (contra ~80 s
    de calibracao completa). Corrigidos docstrings, README e mensagem do
    heading_bench, que diziam que carregar exigia movimento. Consequencia:
    offsets de outra montagem passariam o gate com os contadores a 3
    (OPEN-017). Observada oscilacao do steer com erro em +-180 graus
    (OPEN-018).
    Claude-Session: https://claude.ai/code/session_01XRzXA5CXPFiQgRn2afYE3Y
2026-11-11 Proximos passos: watchdog do ESP32 (OPEN-019), corte remoto independente, INA228
    LEDC continua a pulsar com o CPU bloqueado e o failsafe vive no loop():
    watchdog e teste do ESC sem sinal passam a condicao do ensaio dos
    motores. Corte de potencia por recetor RC e rele normalmente aberto
    revisita a decisao de julho. INA228 + shunt a considerar antes do ACS758.
    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
